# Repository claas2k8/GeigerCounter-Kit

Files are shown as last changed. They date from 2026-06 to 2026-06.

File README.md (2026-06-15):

# Analog Geiger Counter with Multi-Range Meter Output

An Arduino Nano-based analog Geiger counter using an M4011 tube and a moving-coil meter.
The instrument provides four selectable CPM ranges and a meter test mode, producing a 0–1.1 V
analog output through a filtered PWM signal.

---

# Features

- M4011 Geiger-Müller tube support
- Real-time response with exponential filtering
- Smooth analog meter indication
- Four selectable ranges
- Meter CHECK function
- Battery-voltage compensated output
- 1.1 V full-scale output
- Automatic +0.05 V output correction above 0.2 V
- Serial Plotter support
- Pulse debounce protection

---

# Hardware

## Components Used

| Component | Model / Notes |
|---|---|
| Microcontroller | Arduino Nano |
| Geiger counter board | RadiationD-v1.1 (CAJOE) with M4011 tube |
| Analog panel meter | Heschen MODEL DH-670, 0–1 V, Class 2.0 |
| Power | 3 × AA battery holder with cable output (included with CAJOE kit) |
| Range switch | 5-position rotary switch (2-pole; second pole unused) |
| Power switch | Single 3 mm toggle switch |
| Interconnect PCB | Hand-soldered Arduino Nano carrier PCB with expanded pin headers |

### Carrier PCB / GND Rail Note

The hand-soldered carrier PCB multiplies available connections on individual pins, used here
primarily to fan out the GND rail. This is functionally equivalent to a dedicated GND bus strip
and can be replaced by one in any future build.

### Power Switch

The 3 mm toggle switch is wired in the position of the original on-board power switch of the
CAJOE board (where the original SMD switch is located). The switch breaks the battery supply
line and turns the entire unit on and off.

---

## ⚠ Hardware Modification — CAJOE Board R19 (Important)

> **Warning:** The RadiationD-v1.1 (CAJOE) board ships with a resistor at position **R19** that
> forms the pulse output divider. On most boards, this resistor is too high in value, which pulls
> the pulse signal so weakly that the Arduino Nano cannot reliably detect counts — resulting in
> zero or heavily suppressed CPM readings even in the presence of a real radiation source.
>
> **Fix:** Replace R19 with a **10 kΩ resistor**. This lowers the output impedance enough for the
> Nano's digital input to trigger correctly.
>
> This is the single most common reason a CAJOE + Arduino Nano build appears not to work.
> Always verify R19 value and replace it before troubleshooting anything else.

---

---

## Analog Meter Output

**Meter:** Heschen MODEL DH-670, 0–1 V DC, Class 2.0

The meter is driven by the filtered PWM output on **D9**.

```
Full-scale output voltage: 1.1 V
```

The output is deliberately set to 1.1 V at full scale to compensate for the Class 2.0 tolerance
of the DH-670 (±2 % of full scale = ±20 mV). Driving slightly above the nominal 1.0 V ensures a
clearly pegged end-stop indication at maximum reading, leaving no ambiguity about an overrange
condition.

---

## Range Switch

5-position rotary switch (2-pole; only one pole used). Each active position grounds the
corresponding Arduino pin. All inputs use `INPUT_PULLUP`.

| Position | Pin | Range |
|---|-----|---|
| 1 | D4 | 0–100 CPM |
| 2 | D5 | 0–1,000 CPM |
| 3 | D6 | 0–10,000 CPM |
| 4 | D7 | 0–100,000 CPM |
| 5 | D8 | CHECK |

---

# Meter CHECK Mode

Selecting position 5 disconnects the CPM display and runs a continuous meter sweep to verify
meter movement and output circuit integrity.

| Phase | Duration | Output |
|---|---|---|
| Ramp up | 0–5 s | 0 → 1.1 V |
| Ramp down | 5–10 s | 1.1 → 0 V |

The cycle repeats continuously while in CHECK mode.

---

# CPM Processing

Counts are sampled once per second.

**Instantaneous CPM:**
```
InstantCPM = counts_per_second × 60
```

**Filtered display value (exponential moving average):**
```
CPMfiltered = 0.95 × CPMfiltered + 0.05 × CPMinstant
```

This provides:
- Fast response to nearby sources
- Smooth needle movement
- Suppressed single-pulse noise

---

# Output Voltage

For each range:
```
Voltage = 1.1 × (CPMfiltered / FullScale)
```

Correction applied above 0.2 V to compensate for meter non-linearity at low deflections:
```
if Voltage > 0.2 V:
    Voltage += 0.05 V
```

Maximum output is clamped to:
```
1.1 V
```

---

# Battery Voltage Compensation

The Arduino continuously measures its own supply voltage via the internal reference.
PWM duty cycle is automatically scaled:

```
PWM = Voltage × 255 / Vcc
```

This keeps meter calibration nearly constant across:
- USB power (5.0 V)
- Regulated external 5 V supply
- 3 × AA battery pack (voltage sags with discharge)

---

# Serial Plotter

The sketch outputs one line per second in the format:

```
CPM:34.2 Voltage:0.423 Scale:100
```

Open **Tools → Serial Plotter** in the Arduino IDE to view live graphs of CPM, output voltage,
and active range simultaneously.

---

# Pin Assignments

| Function | Pin |
|---|-----|
| Geiger pulse input | D3 |
| Analog meter output (PWM) | D9 |
| Range: 100 CPM | D4 |
| Range: 1,000 CPM | D5 |
| Range: 10,000 CPM | D6 |
| Range: 100,000 CPM | D7 |
| CHECK mode | D8 |

---

# Recommended Components

- Arduino Nano
- RadiationD-v1.1 (CAJOE) Geiger board with M4011 tube
- Heschen MODEL DH-670 0–1 V Class 2.0 analog panel meter
- 5-position rotary switch (1- or 2-pole)
- 3 mm toggle switch (power)
- 3 × AA battery holder with cable
- Hand-soldered carrier PCB or dedicated GND bus strip

---

# Notes

The analog output uses PWM on D9 with an external RC low-pass filter. For lower ripple and
improved linearity, a DAC such as the MCP4725 (I²C, 12-bit) can be substituted for the PWM
output stage.

This instrument is intended for educational and experimental use. It is not calibrated for
radiation protection or dosimetry purposes and should not be used as a substitute for certified
dosimetry equipment.

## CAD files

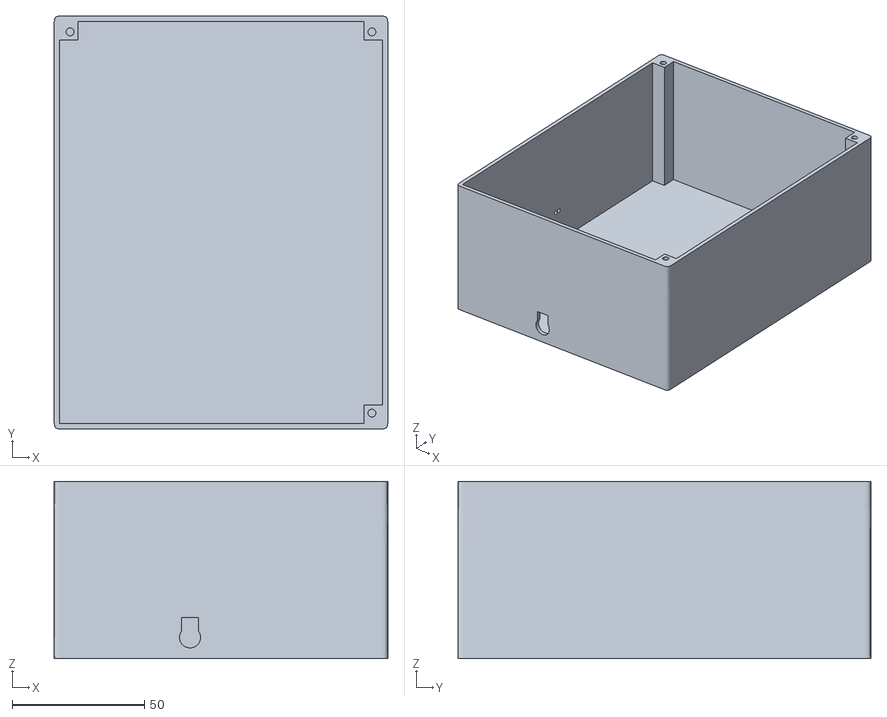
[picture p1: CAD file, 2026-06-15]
Case.stl
126.0 x 156.0 x 67.0

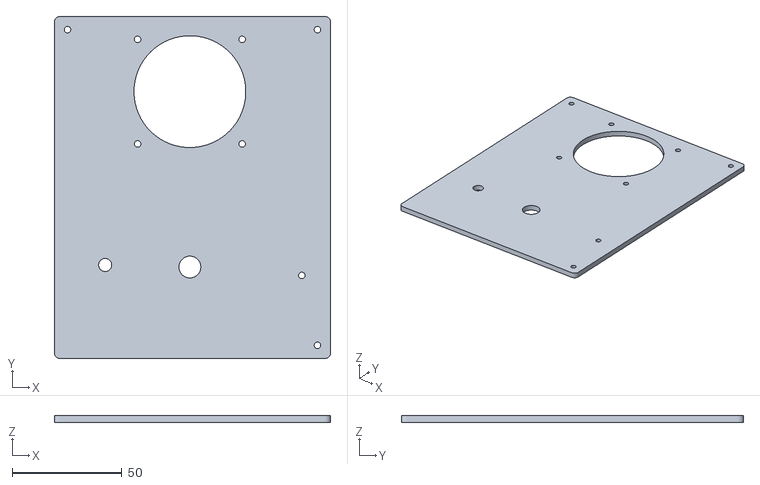
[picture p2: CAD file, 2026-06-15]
Top.stl
126.0 x 156.0 x 3.00

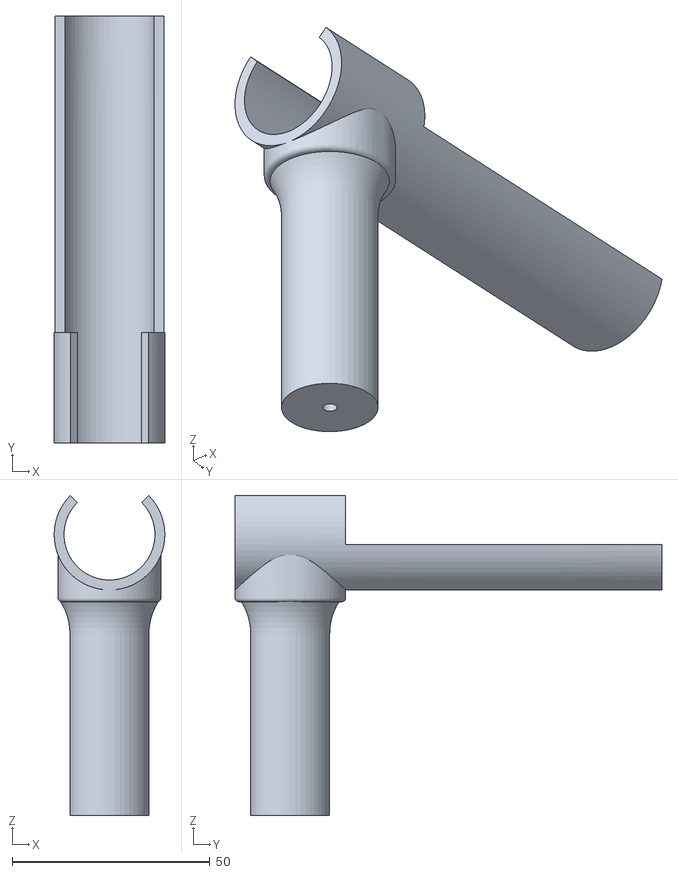
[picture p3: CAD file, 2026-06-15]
Probe holder and handle.stl
28.0 x 108.0 x 81.0

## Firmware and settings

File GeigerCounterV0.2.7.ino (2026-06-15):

const byte INT_PIN = 3;
const byte PWM_PIN = 9;

// Range switch pins
const byte RANGE100_PIN    = 4;
const byte RANGE1000_PIN   = 5;
const byte RANGE10000_PIN  = 6;
const byte RANGE100000_PIN = 7;
const byte CHECK_PIN       = 8;

volatile unsigned long totalPulses = 0;

unsigned long lastSecond = 0;
unsigned long pulsesLastSecond = 0;

// Exponential filter (medium response)
float cpmFiltered = 0.0;

// measured supply voltage
float vccVoltage = 5.0;

void onPulse() {
  static unsigned long last = 0;
  unsigned long now = micros();

  if (now - last < 10000UL)
    return;

  last = now;
  totalPulses++;
}

// Measure Vcc (mV)
long readVcc() {
  ADMUX = _BV(REFS0) | _BV(MUX3) | _BV(MUX2) | _BV(MUX1);
  delay(2);

  ADCSRA |= _BV(ADSC);
  while (bit_is_set(ADCSRA, ADSC));

  long result = ADCL;
  result |= ADCH << 8;

  result = 1125300L / result;
  return result;
}

void setup() {
  Serial.begin(9600);

  pinMode(INT_PIN, INPUT_PULLUP);
  pinMode(PWM_PIN, OUTPUT);

  pinMode(RANGE100_PIN, INPUT_PULLUP);
  pinMode(RANGE1000_PIN, INPUT_PULLUP);
  pinMode(RANGE10000_PIN, INPUT_PULLUP);
  pinMode(RANGE100000_PIN, INPUT_PULLUP);

  pinMode(CHECK_PIN, INPUT_PULLUP);

  attachInterrupt(digitalPinToInterrupt(INT_PIN), onPulse, FALLING);

  lastSecond = millis();

  Serial.println(F("Geiger Meter Ready (Battery Compensated)"));
}

void loop() {

  unsigned long now = millis();

  // ---- update Vcc every 2 seconds ----
  static unsigned long lastVccCheck = 0;
  if (now - lastVccCheck > 2000) {
    vccVoltage = readVcc() / 1000.0;
    lastVccCheck = now;
  }

  // ---- 1-second CPM update ----
  if (now - lastSecond >= 1000) {

    noInterrupts();
    unsigned long currentTotal = totalPulses;
    interrupts();

    unsigned long pulsesThisSecond = currentTotal - pulsesLastSecond;
    pulsesLastSecond = currentTotal;

    float instantCPM = pulsesThisSecond * 60.0;

    cpmFiltered = 0.95 * cpmFiltered + 0.05 * instantCPM;

    lastSecond += 1000;
  }

  float voltage = 0.0;
  float scaleValue = 0.0;   // what we will show as "Scale" in the plotter

  // ---------------- CHECK MODE ----------------
  if (!digitalRead(CHECK_PIN)) {

    float t = (millis() % 10000UL) / 1000.0;

    if (t < 5.0)
      voltage = 1.1 * (t / 5.0);
    else
      voltage = 1.1 * ((10.0 - t) / 5.0);

    scaleValue = 0.0; // CHECK mode indicator
  }

  // ---------------- NORMAL MODE ----------------
  else {

    float fullScale = 100.0;

    if (!digitalRead(RANGE100_PIN))
      fullScale = 100.0;
    else if (!digitalRead(RANGE1000_PIN))
      fullScale = 1000.0;
    else if (!digitalRead(RANGE10000_PIN))
      fullScale = 10000.0;
    else if (!digitalRead(RANGE100000_PIN))
      fullScale = 100000.0;

    scaleValue = fullScale;

    float cpm = cpmFiltered;

    voltage = 1.1 * (cpm / fullScale);

    if (voltage > 0.2)
      voltage += 0.05;

    if (voltage > 1.1)
      voltage = 1.1;
  }

  // ---- BATTERY-COMPENSATED PWM OUTPUT ----
  int pwmValue = (int)(voltage * 255.0 / vccVoltage);

  if (pwmValue > 255)
    pwmValue = 255;
  if (pwmValue < 0)
    pwmValue = 0;

  analogWrite(PWM_PIN, pwmValue);

  // ---- Serial Plotter output: CPM, Voltage, Scale ----
  Serial.print("CPM:");
  Serial.print(cpmFiltered, 1);

  Serial.print(" Voltage:");
  Serial.print(voltage, 3);

  Serial.print(" Scale:");
  Serial.println(scaleValue, 0);

  delay(100);
}

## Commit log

2026-06-14 Revise README for Geiger Counter project
    Updated project description, features, hardware connections, and calibration details in README.
2026-06-15 Update README with analog meter output details
    Clarified output description and adjusted full-scale meter voltage details for accuracy.
2026-06-15 Fix voltage display and wording in README
    Corrected voltage representation and improved clarity.
2026-06-15 STL files of my Printed parts
    [Case.stl, Probe holder and handle.stl, Top.stl]
2026-06-15 Remove Geiger Tube Interface section
    Removed Geiger Tube Interface section from README.
